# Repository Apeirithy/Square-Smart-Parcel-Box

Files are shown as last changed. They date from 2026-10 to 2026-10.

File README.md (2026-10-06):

# Square: Smart & Secure Parcel Box (IoT Edge-to-Cloud System)

An end-to-end Internet of Things (IoT) solution designed to secure residential package deliveries. Built around the ESP32-S3 microcontroller running FreeRTOS, this project integrates multi-sensor edge processing, physical actuation, and Firebase cloud synchronization to provide courier authentication, visual evidence capture, and remote management.

## Project Demonstration
* **Live System Demo & Technical Walkthrough:** [https://youtu.be/-ZhSldYhqhk]

<div align="center">
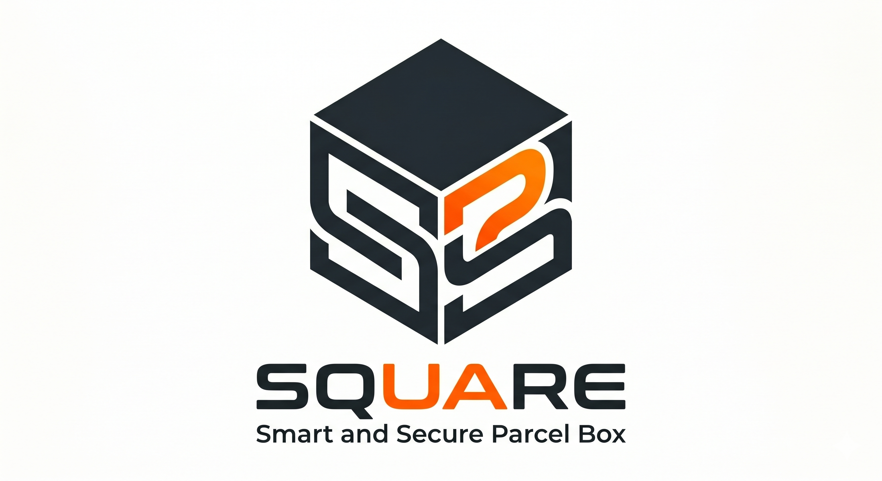
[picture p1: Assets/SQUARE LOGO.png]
Square Logo
  
</div>

## System Architecture & Key Implementations

### 1. Edge Processing & Real-Time Control (FreeRTOS)
The firmware leverages FreeRTOS to manage hardware concurrency and prevent resource collisions across the ESP32-S3's dual cores:
* **Task Isolation:** Separated network operations (Core 0) from time-critical hardware control and UI feedback (Core 1).
* **Multi-Tasking:** Managed independent tasks for Firebase synchronization (`Task_Network`), user input (`Task_Keypad_LED`), security state machine (`Task_StateMachine`), and media processing (`Task_Media`).
* **Resource Protection:** Utilized FreeRTOS Mutexes to secure shared buses (I2C, SPI) and Non-Volatile Storage (NVS) access.

### 2. Multi-Sensor Perception & Actuation
* **Authentication:** A $3\times4$ Matrix Keypad for local PIN input, securely validating against credentials cached in NVS.
* **Visual Evidence:** OV2640 camera captures MJPEG video during door opening and high-res photos upon closure, illuminated by a custom MOSFET-driven High-Power LED flash.
* **State Monitoring:** Magnetic reed switch detects door state, while a VL53L0X Time-of-Flight (ToF) sensor monitors internal capacity.
* **Security:** Actuates a 12V Solenoid lock via an isolated relay module upon successful authentication.

### 3. Cloud Synchronization & Failsafe Mechanisms
* **Firebase RTDB & Cloud Storage:** Synchronizes device status, delivery logs, and large media files (photo/video) using Server-Sent Events (SSE) and HTTPS.
* **Offline Buffering:** In the event of network disruption, all media and logs are buffered to a local MicroSD card using a custom FIFO auto-deletion queue. Uploads automatically resume once connectivity is restored.

<div align="center">
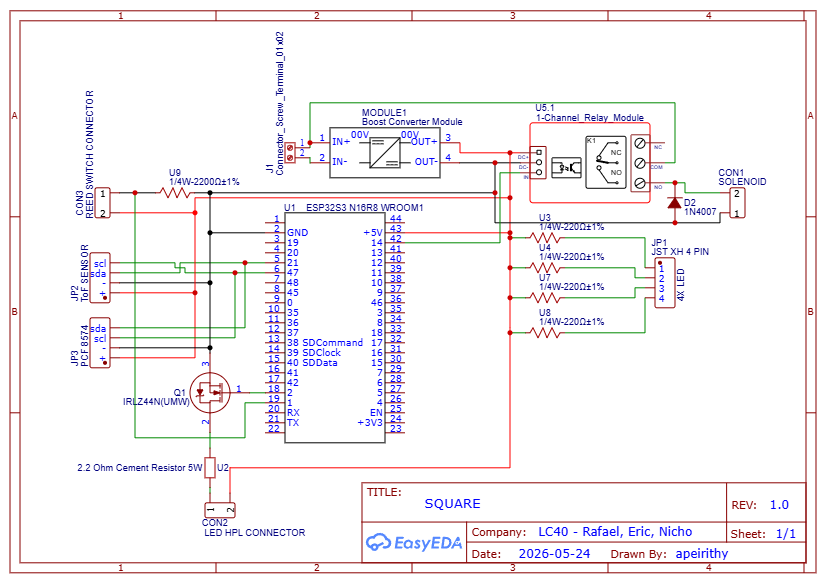
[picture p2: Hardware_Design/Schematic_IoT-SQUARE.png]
Hardware Schematic
  
</div>

## Hardware Engineering
* **Custom Enclosure & Mounts:** Key mechanical components, including camera mounts and sensor brackets, were custom-designed in Tinkercad and 3D printed (PLA).
* **Circuit Design:** Routed and planned the entire electrical schematic via EasyEDA, ensuring safe logic-level isolation for high-current actuators.

## Repository Contents
* **[`/Firmware_src`](./Firmware_src):** ESP32-S3 C++ source code (PlatformIO/Arduino framework).
* **[`/Hardware_Design`](./Hardware_Design):** Circuit schematics and 3D printable `.stl` files.
* **[`/Docs`](./Docs):** Comprehensive technical documentation, including the Final Report, Functional Specification Document (FSD), and Project Proposal.
* **[`/Assets`](./Assets):** Project logo and mobile application interface screenshots.

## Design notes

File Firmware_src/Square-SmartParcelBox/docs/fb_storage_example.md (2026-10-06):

```cpp
/*********
  Rui Santos & Sara Santos - Random Nerd Tutorials
  Complete instructions at: https://RandomNerdTutorials.com/esp32-cam-save-picture-firebase-storage/
  Permission is hereby granted, free of charge, to any person obtaining a copy of this software and associated documentation files. The above copyright notice and this permission notice shall be included in all copies or substantial portions of the Software.
  Based on the example provided by the ESP Firebase Client Library
*********/
#define ENABLE_USER_AUTH
#define ENABLE_STORAGE
#define ENABLE_FS

#include <Arduino.h>
#include <FirebaseClient.h>
#include <FS.h>
#include <LittleFS.h>
#include <WiFi.h>
#include <WiFiClientSecure.h>
#include "esp_camera.h"

#define WIFI_SSID "REPLACE_WITH_YOUR_SSID"
#define WIFI_PASSWORD "REPLACE_WITH_YOUR_PASSWORD"

#define API_KEY "REPLACE_WITH_YOUR_FIREBASE_PROJECT_API_KEY"
#define USER_EMAIL "REPLACE_WITH_FIREBASE_PROJECT_EMAIL_USER"
#define USER_PASSWORD "REPLACE_WITH_FIREBASE_PROJECT_USER_PASS"

// Define the Firebase storage bucket ID e.g bucket-name.appspot.com */
#define STORAGE_BUCKET_ID "REPLACE_WITH_STORAGE_BUCKET_ID"

// Photo path in filesystem and photo path in Firebase bucket
#define FILE_PHOTO_PATH "/photo.jpg"
#define BUCKET_PHOTO_PATH "/data/photo.jpg"

// User functions
void processData(AsyncResult &aResult);
void file_operation_callback(File &file, const char *filename, file_operating_mode mode);

FileConfig media_file(FILE_PHOTO_PATH, file_operation_callback); // Can be set later with media_file.setFile("/image.png", file_operation_callback);

File myFile;

// Authentication
UserAuth user_auth(API_KEY, USER_EMAIL, USER_PASSWORD, 3000 /* expire period in seconds (<3600) */);

// Firebase components
FirebaseApp app;
WiFiClientSecure ssl_client;
using AsyncClient = AsyncClientClass;
AsyncClient aClient(ssl_client);
Storage storage;

bool taskComplete = false;

AsyncResult storageResult;

// OV2640 camera module pins (CAMERA_MODEL_AI_THINKER)
#define PWDN_GPIO_NUM     32
#define RESET_GPIO_NUM    -1
#define XCLK_GPIO_NUM      0
#define SIOD_GPIO_NUM     26
#define SIOC_GPIO_NUM     27
#define Y9_GPIO_NUM       35
#define Y8_GPIO_NUM       34
#define Y7_GPIO_NUM       39
#define Y6_GPIO_NUM       36
#define Y5_GPIO_NUM       21
#define Y4_GPIO_NUM       19
#define Y3_GPIO_NUM       18
#define Y2_GPIO_NUM        5
#define VSYNC_GPIO_NUM    25
#define HREF_GPIO_NUM     23
#define PCLK_GPIO_NUM     22

boolean takeNewPhoto = true;

// Capture Photo and Save it to LittleFS
void capturePhotoSaveLittleFS( void ) {
  // Dispose first pictures because of bad quality
  camera_fb_t* fb = NULL;
  // Skip first 3 frames (increase/decrease number as needed).
  for (int i = 0; i < 10; i++) {
    fb = esp_camera_fb_get();
    esp_camera_fb_return(fb);
    fb = NULL;
  }
    
  // Take a new photo
  fb = NULL;  
  fb = esp_camera_fb_get();  
  if(!fb) {
    Serial.println("Camera capture failed");
    delay(1000);
    ESP.restart();
  }  

  // Photo file name
  Serial.printf("Picture file name: %s\n", FILE_PHOTO_PATH);
  File file = LittleFS.open(FILE_PHOTO_PATH, FILE_WRITE);

  // Insert the data in the photo file
  if (!file) {
    Serial.println("Failed to open file in writing mode");
  }
  else {
    file.write(fb->buf, fb->len); // payload (image), payload length
    Serial.print("The picture has been saved in ");
    Serial.print(FILE_PHOTO_PATH);
    Serial.print(" - Size: ");
    Serial.print(fb->len);
    Serial.println(" bytes");
  }
  // Close the file
  file.close();
  esp_camera_fb_return(fb);
  delay(100);
}

void initLittleFS(){
  if (!LittleFS.begin(true)) {
    Serial.println("An Error has occurred while mounting LittleFS");
    ESP.restart();
  }
  else {
    delay(500);
    Serial.println("LittleFS mounted successfully");
  }
}

void initWiFi(){
  WiFi.begin(WIFI_SSID, WIFI_PASSWORD);
  while (WiFi.status() != WL_CONNECTED) {
    delay(1000);
    Serial.println("Connecting to WiFi...");
  }
}

void initCamera(){
 // OV2640 camera module
  camera_config_t config;
  config.ledc_channel = LEDC_CHANNEL_0;
  config.ledc_timer = LEDC_TIMER_0;
  config.pin_d0 = Y2_GPIO_NUM;
  config.pin_d1 = Y3_GPIO_NUM;
  config.pin_d2 = Y4_GPIO_NUM;
  config.pin_d3 = Y5_GPIO_NUM;
  config.pin_d4 = Y6_GPIO_NUM;
  config.pin_d5 = Y7_GPIO_NUM;
  config.pin_d6 = Y8_GPIO_NUM;
  config.pin_d7 = Y9_GPIO_NUM;
  config.pin_xclk = XCLK_GPIO_NUM;
  config.pin_pclk = PCLK_GPIO_NUM;
  config.pin_vsync = VSYNC_GPIO_NUM;
  config.pin_href = HREF_GPIO_NUM;
  config.pin_sccb_sda = SIOD_GPIO_NUM;
  config.pin_sccb_scl = SIOC_GPIO_NUM;
  config.pin_pwdn = PWDN_GPIO_NUM;
  config.pin_reset = RESET_GPIO_NUM;
  config.xclk_freq_hz = 20000000;
  config.pixel_format = PIXFORMAT_JPEG;
  config.grab_mode = CAMERA_GRAB_LATEST;

  if (psramFound()) {
    config.frame_size = FRAMESIZE_UXGA;
    config.jpeg_quality = 10;
    config.fb_count = 1;
  } else {
    config.frame_size = FRAMESIZE_SVGA;
    config.jpeg_quality = 12;
    config.fb_count = 1;
  }
  // Camera init
  esp_err_t err = esp_camera_init(&config);
  if (err != ESP_OK) {
    Serial.printf("Camera init failed with error 0x%x", err);
    ESP.restart();
  }
  Serial.print("Camera init success");
}

void setup(){
    Serial.begin(115200);
    initWiFi();
    initCamera();

    Firebase.printf("Firebase Client v%s\n", FIREBASE_CLIENT_VERSION);

    initLittleFS();

    // Configure SSL client
    ssl_client.setInsecure();
    ssl_client.setConnectionTimeout(1000);
    ssl_client.setHandshakeTimeout(5);
    Serial.println("Initializing app...");
    initializeApp(aClient, app, getAuth(user_auth), processData, "🔐 authTask");

    app.getApp<Storage>(storage);

    Serial.println("Listing files in LittleFS:");
    File root = LittleFS.open("/");
    File file = root.openNextFile();
    while (file) {
        Serial.println(file.name());
        file = root.openNextFile();
    }

}

void loop(){
    // To maintain the authentication process.
    app.loop();

    if (app.ready() && !taskComplete && takeNewPhoto){
        taskComplete = true;
        takeNewPhoto = false;

        capturePhotoSaveLittleFS();
        
        // Async call with callback function.
        storage.upload(aClient, FirebaseStorage::Parent(STORAGE_BUCKET_ID, BUCKET_PHOTO_PATH), getFile(media_file), "image/jpg", processData, "⬆️  uploadTask");
    }
}

void processData(AsyncResult &aResult)
{
    // Exits when no result available when calling from the loop.
    if (!aResult.isResult())
        return;

    if (aResult.isEvent())
    {
        Firebase.printf("Event task: %s, msg: %s, code: %d\n", aResult.uid().c_str(), aResult.appEvent().message().c_str(), aResult.appEvent().code());
    }

    if (aResult.isDebug())
    {
        Firebase.printf("Debug task: %s, msg: %s\n", aResult.uid().c_str(), aResult.debug().c_str());
    }

    if (aResult.isError())
    {
        Firebase.printf("Error task: %s, msg: %s, code: %d\n", aResult.uid().c_str(), aResult.error().message().c_str(), aResult.error().code());
    }

    if (aResult.downloadProgress())
    {
        Firebase.printf("Downloaded, task: %s, %d%s (%d of %d)\n", aResult.uid().c_str(), aResult.downloadInfo().progress, "%", aResult.downloadInfo().downloaded, aResult.downloadInfo().total);
        if (aResult.downloadInfo().total == aResult.downloadInfo().downloaded)
        {
            Firebase.printf("Download task: %s, complete!✅️\n", aResult.uid().c_str());
        }
    }

    if (aResult.uploadProgress())
    {
        Firebase.printf("Uploaded, task: %s, %d%s (%d of %d)\n", aResult.uid().c_str(), aResult.uploadInfo().progress, "%", aResult.uploadInfo().uploaded, aResult.uploadInfo().total);
        if (aResult.uploadInfo().total == aResult.uploadInfo().uploaded)
        {
            Firebase.printf("Upload task: %s, complete!✅️\n", aResult.uid().c_str());
            Serial.print("Download URL: ");
            Serial.println(aResult.uploadInfo().downloadUrl);
        }
    }
}

void file_operation_callback(File &file, const char *filename, file_operating_mode mode){
    // FILE_OPEN_MODE_READ, FILE_OPEN_MODE_WRITE and FILE_OPEN_MODE_APPEND are defined in this library
    // MY_FS is defined in this example
    switch (mode)    {
    case file_mode_open_read:
        myFile = LittleFS.open(filename, "r");
        if (!myFile || !myFile.available()) {
            Serial.println("[ERROR] Failed to open file for reading");
        }
        break;
    case file_mode_open_write:
        myFile = LittleFS.open(filename, "w");
        break;
    case file_mode_open_append:
        myFile = LittleFS.open(filename, "a");
        break;
    case file_mode_remove:
        LittleFS.remove(filename);
        break;
    default:
        break;
    }
    // Set the internal FS object with global File object.
    file = myFile;
}
```

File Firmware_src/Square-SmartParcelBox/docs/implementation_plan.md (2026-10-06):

# Square Smart Parcel Box — Implementation Plan

## Background

Project ini adalah firmware ESP32-S3 untuk **Square Smart Parcel Box**, sebuah IoT parcel box yang memungkinkan kurir memasukkan paket dengan PIN terbatas, mengambil foto/video bukti, dan menyinkronkan data ke Firebase. Proyek menggunakan **PlatformIO + Arduino framework + FreeRTOS**.

Saat ini proyek masih kosong (hanya skeleton `main.cpp`). Rencana ini memecah seluruh firmware menjadi **10 fase** yang berurutan, di mana setiap fase menghasilkan komponen yang **bisa diuji secara independen** melalui serial monitor dan/atau unit test sederhana.

---

## Open Questions

> [!IMPORTANT]
> **Q1:** Apakah Anda ingin menggunakan framework testing formal (seperti `Unity` test framework bawaan PlatformIO) untuk unit test, atau cukup dengan test manual via serial monitor + sketch test sederhana?

> [!IMPORTANT]
> **Q2:** Apakah credentials (Wi-Fi SSID, Firebase keys, dll.) sudah tersedia dan siap diisi, atau harus dibuat placeholder terlebih dahulu?

> [!IMPORTANT]
> **Q3:** Untuk `upload_queue.txt`, apakah format setiap baris cukup berisi nama file (e.g., `img_1752587495.jpg`) satu per baris?

---

## Proposed Changes

Semua file baru mengikuti struktur dari Section 9 FSD:

```
src/
├── main.cpp
├── pins.h
├── credentials.h
├── config.h
├── hal/
│   ├── ws2812.h / .cpp
│   ├── relay.h / .cpp
│   ├── flash_led.h / .cpp
│   ├── reed_switch.h / .cpp
│   ├── tof.h / .cpp
│   ├── camera.h / .cpp
│   ├── sdcard.h / .cpp
│   ├── keypad_driver.h / .cpp
│   ├── keybuffer_indicator_driver.h / .cpp
│   └── nvs_store.h / .cpp
├── tasks/
│   ├── task_network.h / .cpp
│   ├── task_keypad_led.h / .cpp
│   ├── task_statemachine.h / .cpp
│   └── task_media.h / .cpp
├── state/
│   └── state_machine.h / .cpp
└── firebase/
    ├── fb_rtdb.h / .cpp
    └── fb_storage.h / .cpp
```

---

## Fase 0 — Foundation Files (Pin Definitions, Config, Credentials)

File-file dasar yang menjadi dependensi semua modul lain. **Tidak ada logika yang perlu diuji**, hanya konstanta.

---

### [NEW] [pins.h](file:///c:/Users/rafae/Forgor/ForgorEmbedded/PlatformIO/Square-SmartParcelBox/src/pins.h)

Satu-satunya sumber definisi pin. Semua GPIO, alamat I2C, dan pin PCF8574 didefinisikan di sini.

**Konstanta yang harus didefinisikan:**

| Kategori | Konstanta | Nilai | Catatan |
|---|---|---|---|
| WS2812 | `PIN_LED_WS2812` | `48` | RGB status LED |
| Relay | `PIN_RELAY_SOLENOID` | `14` | Active HIGH |
| Flash | `PIN_AUX_FLASH` | `2` | MOSFET gate |
| Reed Switch | `PIN_DOOR_SWITCH` | `1` | INPUT_PULLUP |
| I2C | `PIN_SDA` | `21` | Shared I2C bus |
| I2C | `PIN_SCL` | `47` | Shared I2C bus |
| I2C Addr | `I2C_ADDR_KEYPAD` | `0x20` | PCF8574 keypad |
| I2C Addr | `I2C_ADDR_LED_IND` | `0x21` | PCF8574 LED |
| I2C Addr | `I2C_ADDR_TOF` | `0x29` | VL53L0X |
| Camera | `PIN_CAM_D0` – `PIN_CAM_D7` | `11,9,8,10,12,18,17,16` | DVP data |
| Camera | `PIN_CAM_XCLK` | `15` | 20MHz clock |
| Camera | `PIN_CAM_PCLK` | `13` | Pixel clock |
| Camera | `PIN_CAM_VSYNC` | `6` | Vertical sync |
| Camera | `PIN_CAM_HREF` | `7` | Horizontal ref |
| Camera | `PIN_CAM_SIOD` | `4` | SCCB data |
| Camera | `PIN_CAM_SIOC` | `5` | SCCB clock |
| SD Card | `PIN_SD_DATA` | `40` | 1-bit mode |
| SD Card | `PIN_SD_CLK` | `39` | Clock |
| SD Card | `PIN_SD_CMD` | `38` | Command |

---

### [NEW] [credentials.h](file:///c:/Users/rafae/Forgor/ForgorEmbedded/PlatformIO/Square-SmartParcelBox/src/credentials.h)

Hardcoded credentials sesuai NCC-006.

**Konstanta yang harus didefinisikan:**

```cpp
#define WIFI_SSID             "your_ssid"
#define WIFI_PASSWORD         "your_password"
#define FIREBASE_DATABASE_URL "project-id-default-rtdb.firebaseio.com"
#define FIREBASE_WEBAPI_KEY   "your_web_api_key"
#define FIREBASE_STORAGE_BUCKET "your_bucket.appspot.com"
#define DEVICE_EMAIL          "device@example.com"
#define DEVICE_PASSWORD       "device_password"
#define USER_UID              "firebase_user_uid"
```

---

### [NEW] [config.h](file:///c:/Users/rafae/Forgor/ForgorEmbedded/PlatformIO/Square-SmartParcelBox/src/config.h)

Non-pin constants: thresholds, timeouts, sizes.

**Konstanta yang harus didefinisikan:**

| Konstanta | Nilai | Sumber FSD |
|---|---|---|
| `TOF_THRESHOLD_CM` | `38` | NCC-001, Section 4.3.7 |
| `TOF_BOX_WIDTH_CM` | `40` | Section 4.3.7 |
| `DOOR_TIMEOUT_MS` | `10000` | SFS-004 |
| `HEARTBEAT_INTERVAL_MS` | `30000` | NCC-008 |
| `WIFI_MAX_RETRIES` | `25` | SFS-006 |
| `WIFI_RETRY_DELAY_MS` | `300` | SFS-006 |
| `FLASH_WARMUP_MS` | `1000` | Section 4.3.5 |
| `SD_MIN_FREE_MB` | `50` | CVL-008 |
| `PIN_LENGTH` | `4` | ACC-001 |
| `RTDB_QUEUE_DEPTH` | `10` | Section 6.5 |
| `COMMAND_QUEUE_DEPTH` | `3` | Section 6.5 |
| `RETRY_FIRST_FAIL_MS` | `300000` (5 min) | Section 4.3.8 |
| `RETRY_SUBSEQUENT_MS` | `900000` (15 min) | Section 4.3.8 |
| `KEYPAD_DEBOUNCE_MS` | `200` | ACC-008 |
| `LED_ALT_INTERVAL_MS` | `250` | Section 4.2.3 |
| `ERROR_LOG_INTERVAL_MS` | `1000` | DBG-012 |
| `WS2812_BLINK_INTERVAL_MS` | `1000` | Section 6.7 |
| `RTOS_MIN_DELAY_MS` | `10` | SFS-009 |

---

## Fase 1 — HAL: Simple Output Drivers (WS2812, Relay, Flash LED)

Driver output sederhana yang **tidak memerlukan I2C** dan bisa diuji langsung.

---

### [NEW] [ws2812.h](file:///c:/Users/rafae/Forgor/ForgorEmbedded/PlatformIO/Square-SmartParcelBox/src/hal/ws2812.h) / [ws2812.cpp](file:///c:/Users/rafae/Forgor/ForgorEmbedded/PlatformIO/Square-SmartParcelBox/src/hal/ws2812.cpp)

WS2812 RGB LED driver. Wrapper around `Adafruit_NeoPixel`.

**Enum yang harus didefinisikan:**

```cpp
enum WS2812Pattern {
    WS2812_OFF,
    WS2812_RED_BLUE_BLINK,   // Startup: blink merah-biru tiap 1 detik
    WS2812_SOLID_BLUE,       // Wi-Fi connected
    WS2812_SOLID_GREEN,      // Firebase connected, no HW issues
    WS2812_SOLID_YELLOW,     // Firebase connected, partial HW issues
    WS2812_SOLID_PURPLE,     // Offline mode with NVS pins
    WS2812_SOLID_RED          // Fatal error / STATE_ERROR
};
```

**Fungsi yang harus dibuat:**

| Fungsi | Signature | Deskripsi | Cara Uji |
|---|---|---|---|
| `ws2812_init` | `bool ws2812_init()` | Inisialisasi NeoPixel pada `PIN_LED_WS2812`. Return `true` jika berhasil. | Panggil di `setup()`, cek LED menyala. |
| `ws2812_set_pattern` | `void ws2812_set_pattern(WS2812Pattern pattern)` | Set pola LED saat ini. Menyimpan pattern ke variable internal. | Panggil dengan berbagai pattern, verifikasi warna LED secara visual. |
| `ws2812_update` | `void ws2812_update()` | Dipanggil di loop task untuk mengupdate animasi (blink). Harus non-blocking, menggunakan `millis()`. | Panggil dalam loop, verifikasi blink bekerja. |

---

### [NEW] [relay.h](file:///c:/Users/rafae/Forgor/ForgorEmbedded/PlatformIO/Square-SmartParcelBox/src/hal/relay.h) / [relay.cpp](file:///c:/Users/rafae/Forgor/ForgorEmbedded/PlatformIO/Square-SmartParcelBox/src/hal/relay.cpp)

Solenoid relay driver. Active HIGH.

**Fungsi yang harus dibuat:**

| Fungsi | Signature | Deskripsi | Cara Uji |
|---|---|---|---|
| `relay_init` | `bool relay_init()` | Inisialisasi GPIO `PIN_RELAY_SOLENOID` sebagai OUTPUT, set LOW (locked). Return `true`. | Panggil di `setup()`, pastikan solenoid terkunci. |
| `relay_unlock` | `void relay_unlock()` | Set pin HIGH untuk membuka solenoid. | Panggil, verifikasi solenoid terbuka. |
| `relay_lock` | `void relay_lock()` | Set pin LOW untuk mengunci solenoid. | Panggil, verifikasi solenoid terkunci. |
| `relay_is_unlocked` | `bool relay_is_unlocked()` | Return status pin saat ini (`HIGH` = unlocked). | Panggil setelah `unlock`/`lock`, verifikasi via Serial. |

---

### [NEW] [flash_led.h](file:///c:/Users/rafae/Forgor/ForgorEmbedded/PlatformIO/Square-SmartParcelBox/src/hal/flash_led.h) / [flash_led.cpp](file:///c:/Users/rafae/Forgor/ForgorEmbedded/PlatformIO/Square-SmartParcelBox/src/hal/flash_led.cpp)

Auxiliary flash LED driver (MOSFET-driven). Active HIGH.

**Fungsi yang harus dibuat:**

| Fungsi | Signature | Deskripsi | Cara Uji |
|---|---|---|---|
| `flash_led_init` | `bool flash_led_init()` | Inisialisasi GPIO `PIN_AUX_FLASH` sebagai OUTPUT, set LOW (off). Return `true`. | Panggil di `setup()`. |
| `flash_led_on` | `void flash_led_on()` | Nyalakan flash LED (HIGH). | Panggil, verifikasi LED menyala. |
| `flash_led_off` | `void flash_led_off()` | Matikan flash LED (LOW). | Panggil, verifikasi LED mati. |

---

## Fase 2 — HAL: Simple Input Driver (Reed Switch)

---

### [NEW] [reed_switch.h](file:///c:/Users/rafae/Forgor/ForgorEmbedded/PlatformIO/Square-SmartParcelBox/src/hal/reed_switch.h) / [reed_switch.cpp](file:///c:/Users/rafae/Forgor/ForgorEmbedded/PlatformIO/Square-SmartParcelBox/src/hal/reed_switch.cpp)

Magnetic reed switch driver. Closed = HIGH, Open = LOW.

**Fungsi yang harus dibuat:**

| Fungsi | Signature | Deskripsi | Cara Uji |
|---|---|---|---|
| `reed_switch_init` | `bool reed_switch_init()` | Inisialisasi GPIO `PIN_DOOR_SWITCH` sebagai `INPUT_PULLUP`. Return `true`. | Panggil di `setup()`. |
| `reed_switch_is_closed` | `bool reed_switch_is_closed()` | Return `true` jika pin HIGH (pintu tertutup). | Buka/tutup pintu, print ke Serial. |
| `reed_switch_is_open` | `bool reed_switch_is_open()` | Return `true` jika pin LOW (pintu terbuka). Kebalikan dari `is_closed`. | Buka/tutup pintu, print ke Serial. |

---

## Fase 3 — HAL: I2C Drivers (Keypad, LED Indicator, ToF)

Semua perangkat I2C pada bus yang sama. Memerlukan `I2C_Mutex` untuk akses bersama, tetapi di fase ini diuji **tanpa mutex** (single-threaded).

---

### [NEW] [keypad_driver.h](file:///c:/Users/rafae/Forgor/ForgorEmbedded/PlatformIO/Square-SmartParcelBox/src/hal/keypad_driver.h) / [keypad_driver.cpp](file:///c:/Users/rafae/Forgor/ForgorEmbedded/PlatformIO/Square-SmartParcelBox/src/hal/keypad_driver.cpp)

Custom 3x4 matrix keypad library via PCF8574 (ACC-009). Mengimplementasi row-scanning dengan debounce (ACC-008).

**Fungsi yang harus dibuat:**

| Fungsi | Signature | Deskripsi | Cara Uji |
|---|---|---|---|
| `keypad_init` | `bool keypad_init(TwoWire &wire)` | Inisialisasi I2C pada alamat `I2C_ADDR_KEYPAD`. Verifikasi PCF8574 merespons. Return `true`/`false`. | Panggil di `setup()`, cek log `SUCCESS`/`FAILED`. |
| `keypad_scan` | `char keypad_scan()` | Scan satu siklus penuh matrix keypad. Return karakter tombol yang ditekan (`'0'`–`'9'`, `'*'`, `'#'`) atau `'\0'` jika tidak ada. Implementasi debounce internal. HARUS mengabaikan `'*'` dan `'#'` (ACC-010). | Panggil dalam loop, print karakter ke Serial. Verifikasi setiap tekan = satu karakter (ACC-008). |
| `keypad_is_available` | `bool keypad_is_available()` | Return `true` jika init berhasil dan PCF8574 merespons. | Cabut I2C, verifikasi return `false`. |

**Detail implementasi `keypad_scan`:**
1. Untuk setiap row (R1-R4): set row LOW, baca kolom (C1-C3).
2. Jika ada kolom LOW, decode posisi ke karakter.
3. Debounce: hanya return karakter jika tombol stabil selama `KEYPAD_DEBOUNCE_MS`.
4. Edge detection: hanya return karakter pada transisi press→release atau idle→press, BUKAN saat hold.
5. Ignore `'*'` dan `'#'` → return `'\0'`.

---

### [NEW] [keybuffer_indicator_driver.h](file:///c:/Users/rafae/Forgor/ForgorEmbedded/PlatformIO/Square-SmartParcelBox/src/hal/keybuffer_indicator_driver.h) / [keybuffer_indicator_driver.cpp](file:///c:/Users/rafae/Forgor/ForgorEmbedded/PlatformIO/Square-SmartParcelBox/src/hal/keybuffer_indicator_driver.cpp)

4x LED indicator via PCF8574 (Active LOW).

**Fungsi yang harus dibuat:**

| Fungsi | Signature | Deskripsi | Cara Uji |
|---|---|---|---|
| `led_indicator_init` | `bool led_indicator_init(TwoWire &wire)` | Inisialisasi I2C pada alamat `I2C_ADDR_LED_IND`. Set semua LED OFF (all bits HIGH karena active LOW). Return `true`/`false`. | Panggil, verifikasi semua LED mati. |
| `led_indicator_set_count` | `void led_indicator_set_count(uint8_t count)` | Nyalakan LED 0 s/d `count-1`. `count=0` semua mati, `count=4` semua nyala. | Panggil dengan 0–4, verifikasi visual. |
| `led_indicator_all_off` | `void led_indicator_all_off()` | Matikan semua LED. Shortcut untuk `set_count(0)`. | Verifikasi visual. |
| `led_indicator_alternating_pattern` | `void led_indicator_alternating_pattern()` | Animasi bergantian kiri-kanan sesuai Section 4.2.3 (250ms interval). Non-blocking, gunakan `millis()`. | Panggil dalam loop, verifikasi pola. |
| `led_indicator_stop_pattern` | `void led_indicator_stop_pattern()` | Hentikan pola animasi dan matikan semua LED. | Panggil setelah animasi berjalan. |
| `led_indicator_is_available` | `bool led_indicator_is_available()` | Return `true` jika init berhasil. | Cek return value. |

---

### [NEW] [tof.h](file:///c:/Users/rafae/Forgor/ForgorEmbedded/PlatformIO/Square-SmartParcelBox/src/hal/tof.h) / [tof.cpp](file:///c:/Users/rafae/Forgor/ForgorEmbedded/PlatformIO/Square-SmartParcelBox/src/hal/tof.cpp)

VL53L0X Time-of-Flight sensor driver via `Adafruit_VL53L0X`.

**Fungsi yang harus dibuat:**

| Fungsi | Signature | Deskripsi | Cara Uji |
|---|---|---|---|
| `tof_init` | `bool tof_init(TwoWire &wire)` | Inisialisasi VL53L0X pada alamat `I2C_ADDR_TOF`. Return `true`/`false`. | Panggil, cek log. |
| `tof_read_distance_cm` | `int16_t tof_read_distance_cm()` | Baca jarak dalam cm. Return `-1` jika gagal/timeout. | Letakkan objek di depan sensor, print jarak. |
| `tof_is_full` | `bool tof_is_full()` | Return `true` jika `tof_read_distance_cm() < TOF_THRESHOLD_CM`. Sesuai NCC-001. | Blokir/buka sensor, verifikasi output. |
| `tof_is_available` | `bool tof_is_available()` | Return `true` jika init berhasil. | Cek return value. |

---

## Fase 4 — HAL: Camera & SD Card

Komponen yang lebih kompleks, masing-masing memiliki banyak fungsi.

---

### [NEW] [camera.h](file:///c:/Users/rafae/Forgor/ForgorEmbedded/PlatformIO/Square-SmartParcelBox/src/hal/camera.h) / [camera.cpp](file:///c:/Users/rafae/Forgor/ForgorEmbedded/PlatformIO/Square-SmartParcelBox/src/hal/camera.cpp)

OV2640 camera driver. Mendukung foto (UXGA/JPG 1600×1200) dan video (VGA/MJPEG 640×480).

**Fungsi yang harus dibuat:**

| Fungsi | Signature | Deskripsi | Cara Uji |
|---|---|---|---|
| `camera_init` | `bool camera_init()` | Inisialisasi kamera OV2640 dengan konfigurasi pin dari `pins.h`. Gunakan PSRAM untuk frame buffer. Default resolusi UXGA JPG. Return `true`/`false`. | Panggil, cek log SUCCESS/FAILED. |
| `camera_capture_photo` | `camera_fb_t* camera_capture_photo()` | Set resolusi ke UXGA, ambil satu frame. Return pointer ke frame buffer (caller harus memanggil `camera_return_fb`). Return `NULL` jika gagal. | Panggil, verifikasi `fb->len > 0`. |
| `camera_return_fb` | `void camera_return_fb(camera_fb_t* fb)` | Kembalikan frame buffer ke pool. | Panggil setelah `capture_photo`. |
| `camera_set_resolution_photo` | `void camera_set_resolution_photo()` | Set resolusi ke UXGA (1600×1200) JPG. | Panggil, ambil foto, verifikasi resolusi. |
| `camera_set_resolution_video` | `void camera_set_resolution_video()` | Set resolusi ke VGA (640×480) JPG (untuk MJPEG frames). | Panggil, ambil frame, verifikasi resolusi. |
| `camera_is_available` | `bool camera_is_available()` | Return `true` jika init berhasil. | Cek return value. |

---

### [NEW] [sdcard.h](file:///c:/Users/rafae/Forgor/ForgorEmbedded/PlatformIO/Square-SmartParcelBox/src/hal/sdcard.h) / [sdcard.cpp](file:///c:/Users/rafae/Forgor/ForgorEmbedded/PlatformIO/Square-SmartParcelBox/src/hal/sdcard.cpp)

MicroSD card driver. 1-bit SD_MMC mode. Mencakup file I/O, upload queue, dan FIFO cleanup.

**Fungsi yang harus dibuat:**

| Fungsi | Signature | Deskripsi | Cara Uji |
|---|---|---|---|
| `sdcard_init` | `bool sdcard_init()` | Mount SD card via `SD_MMC` 1-bit mode. Log tipe dan ukuran kartu (DBG-010). Return `true`/`false`. | Panggil, cek log. |
| `sdcard_write_test` | `bool sdcard_write_test()` | Tulis dan baca file dummy untuk verifikasi (DBG-008). Return `true` jika PASSED. | Panggil, cek log. |
| `sdcard_save_file` | `bool sdcard_save_file(const char* dir_path, const char* filename, const uint8_t* data, size_t len)` | Buat direktori `dir_path` jika belum ada, tulis data ke `dir_path/filename`. Return `true`/`false`. | Tulis data dummy, baca kembali, bandingkan. |
| `sdcard_read_file` | `bool sdcard_read_file(const char* filepath, uint8_t** out_data, size_t* out_len)` | Baca file ke buffer yang di-allocate (caller harus `free()`). Return `true`/`false`. | Baca file yang sudah ditulis, verifikasi isi. |
| `sdcard_file_exists` | `bool sdcard_file_exists(const char* filepath)` | Cek apakah file ada. | Cek file yang ada dan tidak ada. |
| `sdcard_delete_file` | `bool sdcard_delete_file(const char* filepath)` | Hapus file. Return `true`/`false`. | Hapus file, verifikasi tidak ada lagi. |
| `sdcard_delete_dir` | `bool sdcard_delete_dir(const char* dir_path)` | Hapus direktori beserta isinya. Return `true`/`false`. | Buat dir+file, hapus dir, verifikasi. |
| `sdcard_get_free_mb` | `uint32_t sdcard_get_free_mb()` | Return sisa ruang kosong dalam MB. | Print, verifikasi masuk akal. |
| `sdcard_queue_push_back` | `bool sdcard_queue_push_back(const char* filename)` | Tambahkan `filename` ke akhir `upload_queue.txt`. | Tambah beberapa entry, baca file, verifikasi urutan. |
| `sdcard_queue_push_front` | `bool sdcard_queue_push_front(const char* filename)` | Tambahkan `filename` ke depan `upload_queue.txt` (untuk prioritas on-demand). | Tambah entry, verifikasi posisi pertama. |
| `sdcard_queue_pop_front` | `bool sdcard_queue_pop_front(char* out_filename, size_t max_len)` | Ambil dan hapus entry pertama dari `upload_queue.txt`. Return `true` jika ada entry. | Push beberapa, pop satu per satu, verifikasi urutan FIFO. |
| `sdcard_queue_peek_front` | `bool sdcard_queue_peek_front(char* out_filename, size_t max_len)` | Lihat entry pertama tanpa menghapus. | Peek, verifikasi tidak hilang setelah peek. |
| `sdcard_queue_remove` | `bool sdcard_queue_remove(const char* filename)` | Hapus entry spesifik dari queue (untuk abort on-demand). | Push 3, remove tengah, verifikasi. |
| `sdcard_queue_is_empty` | `bool sdcard_queue_is_empty()` | Return `true` jika queue kosong. | Cek saat kosong dan saat ada isi. |
| `sdcard_fifo_cleanup` | `void sdcard_fifo_cleanup()` | Paired FIFO deletion (CVL-007, CVL-008): hapus pasangan img+vid terlama sampai free space ≥ `SD_MIN_FREE_MB`. | Buat banyak file dummy, panggil cleanup, verifikasi file terlama terhapus. |
| `sdcard_is_available` | `bool sdcard_is_available()` | Return `true` jika init berhasil. | Cek return value. |
| `sdcard_get_type_string` | `const char* sdcard_get_type_string()` | Return string tipe kartu ("SDHC", "SD", dll). | Print ke Serial. |
| `sdcard_get_size_mb` | `uint32_t sdcard_get_size_mb()` | Return ukuran kartu dalam MB. | Print ke Serial. |

---

## Fase 5 — HAL: NVS Storage

---

### [NEW] [nvs_store.h](file:///c:/Users/rafae/Forgor/ForgorEmbedded/PlatformIO/Square-SmartParcelBox/src/hal/nvs_store.h) / [nvs_store.cpp](file:///c:/Users/rafae/Forgor/ForgorEmbedded/PlatformIO/Square-SmartParcelBox/src/hal/nvs_store.cpp)

NVS Preferences wrapper untuk menyimpan active_pins sebagai JSON string (max 512 bytes). Menggunakan `ArduinoJson` untuk serialisasi.

**Fungsi yang harus dibuat:**

| Fungsi | Signature | Deskripsi | Cara Uji |
|---|---|---|---|
| `nvs_store_init` | `bool nvs_store_init()` | Inisialisasi Preferences namespace. Baca `active_pins` string jika ada. Return `true`/`false`. Log jumlah PIN aktif (DBG-011). | Panggil, cek log. |
| `nvs_store_get_pin_count` | `int nvs_store_get_pin_count()` | Return jumlah PIN aktif yang tersimpan. | Tambah PIN, verifikasi count. |
| `nvs_store_has_pins` | `bool nvs_store_has_pins()` | Return `true` jika ada minimal 1 PIN aktif. | Cek saat kosong dan saat ada PIN. |
| `nvs_store_verify_pin` | `bool nvs_store_verify_pin(const char* pin)` | Verifikasi PIN: return `true` jika PIN ada dan `used_quota < quota`. | Simpan PIN q=3 u=1, verifikasi true. Simpan PIN q=1 u=1, verifikasi false. |
| `nvs_store_increment_used` | `bool nvs_store_increment_used(const char* pin)` | Increment `used_quota` PIN. Jika `used_quota >= quota`, hapus PIN dari NVS (ACC-007). Return `true` jika berhasil. | Increment, cek count berkurang setelah habis. |
| `nvs_store_get_remaining_quota` | `int nvs_store_get_remaining_quota(const char* pin)` | Return sisa quota (`quota - used_quota`). Return `-1` jika PIN tidak ditemukan. | Cek sebelum/sesudah increment. |
| `nvs_store_save_pin` | `bool nvs_store_save_pin(const char* pin, int quota, int used_quota)` | Simpan/update satu PIN ke NVS. | Simpan, baca kembali, verifikasi. |
| `nvs_store_save_all_pins` | `bool nvs_store_save_all_pins(const char* json_str)` | Overwrite seluruh `active_pins` dengan JSON string baru (untuk sinkronisasi dari Firebase). | Simpan JSON, baca count, verifikasi. |
| `nvs_store_get_all_pins_json` | `String nvs_store_get_all_pins_json()` | Return JSON string dari semua active_pins saat ini. | Print ke Serial, verifikasi format. |
| `nvs_store_delete_pin` | `bool nvs_store_delete_pin(const char* pin)` | Hapus satu PIN spesifik dari NVS. | Hapus, verifikasi count berkurang. |
| `nvs_store_clear_all` | `void nvs_store_clear_all()` | Hapus semua PIN (untuk debugging). | Panggil, verifikasi `has_pins()` false. |
| `nvs_store_is_available` | `bool nvs_store_is_available()` | Return `true` jika init berhasil. | Cek return value. |

---

## Fase 6 — State Machine

---

### [NEW] [state_machine.h](file:///c:/Users/rafae/Forgor/ForgorEmbedded/PlatformIO/Square-SmartParcelBox/src/state/state_machine.h) / [state_machine.cpp](file:///c:/Users/rafae/Forgor/ForgorEmbedded/PlatformIO/Square-SmartParcelBox/src/state/state_machine.cpp)

State enum dan transition logic sesuai Section 6.6.

**Enum yang harus didefinisikan:**

```cpp
enum SystemState {
    STATE_START,
    STATE_IDLE,
    STATE_DELIVERY,
    STATE_ONDEMAND,
    STATE_ERROR
};

// Command enum untuk CommandQueue
enum RemoteCommand {
    CMD_NONE,
    CMD_UNLOCK,
    CMD_LOCK,
    CMD_LOCK_AND_UNLOCK,   // Conflict: prioritas lock (Section 5.1)
    CMD_REQUEST_PHOTO,
    CMD_REQUEST_VIDEO
};
```

**Fungsi yang harus dibuat:**

| Fungsi | Signature | Deskripsi | Cara Uji |
|---|---|---|---|
| `sm_init` | `void sm_init()` | Set state awal ke `STATE_START`. | Panggil, cek state. |
| `sm_get_state` | `SystemState sm_get_state()` | Return state saat ini. | Cek setelah init. |
| `sm_transition_to` | `bool sm_transition_to(SystemState new_state)` | Validasi dan eksekusi transisi. Return `false` jika transisi illegal (e.g., dari `STATE_ERROR` ke manapun). Log transisi ke Serial. | Coba semua transisi valid dan invalid. |
| `sm_is_idle` | `bool sm_is_idle()` | Shortcut: return `state == STATE_IDLE`. | Cek di berbagai state. |
| `sm_is_error` | `bool sm_is_error()` | Shortcut: return `state == STATE_ERROR`. | Cek di berbagai state. |
| `sm_get_state_name` | `const char* sm_get_state_name(SystemState state)` | Return string nama state untuk logging (e.g., `"STATE_IDLE"`). | Print semua state names. |

**Tabel transisi valid (enforce di `sm_transition_to`):**

| From | To | Valid? |
|---|---|---|
| `STATE_START` | `STATE_IDLE` | ✅ |
| `STATE_START` | `STATE_ERROR` | ✅ |
| `STATE_IDLE` | `STATE_DELIVERY` | ✅ |
| `STATE_IDLE` | `STATE_ONDEMAND` | ✅ |
| `STATE_IDLE` | `STATE_ERROR` | ✅ |
| `STATE_DELIVERY` | `STATE_IDLE` | ✅ |
| `STATE_DELIVERY` | `STATE_ERROR` | ✅ |
| `STATE_ONDEMAND` | `STATE_IDLE` | ✅ |
| `STATE_ERROR` | * | ❌ (dead state) |

---

## Fase 7 — Firebase Modules

---

### [NEW] [fb_rtdb.h](file:///c:/Users/rafae/Forgor/ForgorEmbedded/PlatformIO/Square-SmartParcelBox/src/firebase/fb_rtdb.h) / [fb_rtdb.cpp](file:///c:/Users/rafae/Forgor/ForgorEmbedded/PlatformIO/Square-SmartParcelBox/src/firebase/fb_rtdb.cpp)

Semua operasi Firebase Realtime Database. Menggunakan `FirebaseClient` library.

**Fungsi yang harus dibuat:**

| Fungsi | Signature | Deskripsi | Cara Uji |
|---|---|---|---|
| `fb_rtdb_init` | `bool fb_rtdb_init()` | Autentikasi Firebase via email/password (`DEVICE_EMAIL`, `DEVICE_PASSWORD`). Setup SSL client. Return `true`/`false`. | Panggil, cek log autentikasi berhasil. |
| `fb_rtdb_create_device_entry` | `bool fb_rtdb_create_device_entry(const char* mac_address)` | Buat entry device baru di RTDB path `users/{USER_UID}/devices/{mac_address}/` dengan sub-entry kosong (delivery_logs, remote_sync, status). | Panggil, verifikasi di Firebase Console. |
| `fb_rtdb_update_heartbeat` | `bool fb_rtdb_update_heartbeat(const char* mac_address, const char* timestamp)` | Update `status/last_heartbeat` dengan timestamp saat ini. | Panggil tiap 30 detik, verifikasi di Console. |
| `fb_rtdb_update_status` | `bool fb_rtdb_update_status(const char* mac_address, const char* key, bool value)` | Update field status (`isOpen`, `isUnlocked`, `isFull`). | Update, verifikasi di Console. |
| `fb_rtdb_add_delivery_log` | `bool fb_rtdb_add_delivery_log(const char* mac_address, const char* timestamp, const char* used_pin, const char* event_type, const char* photo_url)` | Tambah entry delivery log baru. | Tambah, verifikasi di Console. |
| `fb_rtdb_update_delivery_video_url` | `bool fb_rtdb_update_delivery_video_url(const char* mac_address, const char* timestamp, const char* video_url)` | Update `video_evidence_url` pada delivery log tertentu. | Update, verifikasi di Console. |
| `fb_rtdb_stream_start` | `bool fb_rtdb_stream_start(const char* mac_address)` | Start SSE stream pada path `users/{USER_UID}/devices/{mac_address}/remote_sync`. | Panggil, verifikasi koneksi di log. |
| `fb_rtdb_stream_loop` | `void fb_rtdb_stream_loop()` | Proses event stream. Parse data yang masuk dan kirim ke CommandQueue / update NVS pins. | Ubah data di Console, verifikasi event diterima. |
| `fb_rtdb_is_connected` | `bool fb_rtdb_is_connected()` | Return `true` jika autentikasi sukses dan koneksi aktif. | Cek saat connected/disconnected. |
| `fb_rtdb_clear_command` | `bool fb_rtdb_clear_command(const char* mac_address, const char* command_key, const char* reset_value)` | Reset command field (`unlock`→`false`, `request_video_id`→`""`, dll). | Reset, verifikasi di Console. |
| `fb_rtdb_increment_pin_used_quota` | `bool fb_rtdb_increment_pin_used_quota(const char* mac_address, const char* pin)` | Increment `used_quota` PIN di Firebase (ACC-006). | Increment, verifikasi di Console. |
| `fb_rtdb_delete_pin` | `bool fb_rtdb_delete_pin(const char* mac_address, const char* pin)` | Hapus PIN dari Firebase (ACC-007). | Hapus, verifikasi di Console. |
| `fb_rtdb_get_mac_address` | `String fb_rtdb_get_mac_address()` | Return MAC address ESP32 sebagai string hex 12-digit tanpa separator. | Print, verifikasi. |

---

### [NEW] [fb_storage.h](file:///c:/Users/rafae/Forgor/ForgorEmbedded/PlatformIO/Square-SmartParcelBox/src/firebase/fb_storage.h) / [fb_storage.cpp](file:///c:/Users/rafae/Forgor/ForgorEmbedded/PlatformIO/Square-SmartParcelBox/src/firebase/fb_storage.cpp)

Firebase Cloud Storage upload operations.

**Fungsi yang harus dibuat:**

| Fungsi | Signature | Deskripsi | Cara Uji |
|---|---|---|---|
| `fb_storage_init` | `bool fb_storage_init()` | Setup Firebase Storage client. Return `true`/`false`. | Panggil, cek log. |
| `fb_storage_upload_file` | `String fb_storage_upload_file(const char* mac_address, const char* timestamp, const char* local_filepath, const char* content_type)` | Upload file dari SD card ke path `users/{USER_UID}/devices/{mac_address}/storage/{timestamp}/{filename}`. Return download URL jika sukses, empty string jika gagal. | Upload foto test, verifikasi di Firebase Console. |
| `fb_storage_is_available` | `bool fb_storage_is_available()` | Return `true` jika init berhasil. | Cek return value. |

---

## Fase 8 — RTOS IPC (Queues & Mutexes)

Mendefinisikan dan membuat semua RTOS primitif sebelum task dibuat.

---

### RTOS IPC — Didefinisikan di [main.cpp](file:///c:/Users/rafae/Forgor/ForgorEmbedded/PlatformIO/Square-SmartParcelBox/src/main.cpp) sebagai global

**Objek RTOS yang harus dibuat (sebagai `extern` di header masing-masing task):**

| Nama | Tipe | Konfigurasi | Digunakan Oleh |
|---|---|---|---|
| `RTDBQueue` | `QueueHandle_t` | Depth: 10, item size: struct `RTDBWriteRequest` | Task_Network (consumer), Task_StateMachine (producer) |
| `CommandQueue` | `QueueHandle_t` | Depth: 3, item size: `RemoteCommand` enum | Task_Network (producer), Task_StateMachine (consumer) |
| `I2C_Mutex` | `SemaphoreHandle_t` | Mutex | Task_Keypad_LED, Task_StateMachine (ToF) |
| `SD_Mutex` | `SemaphoreHandle_t` | Mutex | Task_Network, Task_Media |
| `NVS_Mutex` | `SemaphoreHandle_t` | Mutex | Task_Network, Task_StateMachine |

**Struct untuk RTDBQueue:**

```cpp
enum RTDBWriteType {
    RTDB_HEARTBEAT,
    RTDB_STATUS_BOOL,
    RTDB_DELIVERY_LOG,
    RTDB_CLEAR_COMMAND,
    RTDB_INCREMENT_PIN,
    RTDB_DELETE_PIN,
    RTDB_UPDATE_VIDEO_URL
};

struct RTDBWriteRequest {
    RTDBWriteType type;
    char key[32];          // status key or PIN or command key
    char value_str[128];   // timestamp, URL, etc.
    bool value_bool;       // for boolean status
};
```

**Cara Uji:** Buat program test sederhana yang membuat queue, push/pop item, verifikasi via Serial.

---

## Fase 9 — RTOS Tasks

Setiap task berjalan di core yang ditentukan sesuai Section 6.4.

---

### [NEW] [task_keypad_led.h](file:///c:/Users/rafae/Forgor/ForgorEmbedded/PlatformIO/Square-SmartParcelBox/src/tasks/task_keypad_led.h) / [task_keypad_led.cpp](file:///c:/Users/rafae/Forgor/ForgorEmbedded/PlatformIO/Square-SmartParcelBox/src/tasks/task_keypad_led.cpp)

**Priority 4 (Highest), Core 1.** I2C: Keypad + LED Indicator.

**Fungsi yang harus dibuat:**

| Fungsi | Signature | Deskripsi | Cara Uji |
|---|---|---|---|
| `task_keypad_led_entry` | `void task_keypad_led_entry(void* pvParameters)` | FreeRTOS task entry point. Loop: scan keypad (dengan I2C_Mutex), update LED count, jika 4 digit terkumpul → set flag/notify Task_StateMachine. | Jalankan task, tekan tombol, verifikasi LED dan log Serial. |
| `task_keypad_led_get_buffer` | `const char* task_keypad_led_get_buffer()` | Return pointer ke 4-digit buffer saat ini. | Tekan 4 digit, baca buffer. |
| `task_keypad_led_clear_buffer` | `void task_keypad_led_clear_buffer()` | Reset buffer ke kosong dan matikan semua LED. | Panggil, verifikasi buffer kosong. |
| `task_keypad_led_is_buffer_full` | `bool task_keypad_led_is_buffer_full()` | Return `true` jika 4 digit sudah dimasukkan. | Tekan 4 digit, verifikasi. |
| `task_keypad_led_set_enabled` | `void task_keypad_led_set_enabled(bool enabled)` | Enable/disable scanning (disable saat tidak di STATE_IDLE). | Disable, tekan tombol, verifikasi tidak terekam. |

**Loop utama:**
1. `vTaskDelay(pdMS_TO_TICKS(RTOS_MIN_DELAY_MS))` (SFS-009)
2. Acquire `I2C_Mutex`
3. `key = keypad_scan()`
4. Jika `key != '\0'`: tambah ke buffer, update `led_indicator_set_count(buffer_len)`
5. Release `I2C_Mutex`
6. Jika `buffer_len == 4`: set flag `buffer_full = true`

---

### [NEW] [task_statemachine.h](file:///c:/Users/rafae/Forgor/ForgorEmbedded/PlatformIO/Square-SmartParcelBox/src/tasks/task_statemachine.h) / [task_statemachine.cpp](file:///c:/Users/rafae/Forgor/ForgorEmbedded/PlatformIO/Square-SmartParcelBox/src/tasks/task_statemachine.cpp)

**Priority 3, Core 1.** Central coordinator.

**Fungsi yang harus dibuat:**

| Fungsi | Signature | Deskripsi | Cara Uji |
|---|---|---|---|
| `task_sm_entry` | `void task_sm_entry(void* pvParameters)` | FreeRTOS task entry point. Main state machine loop. | Jalankan, monitor transisi state via Serial. |
| `task_sm_handle_idle` | `void task_sm_handle_idle()` | Handle STATE_IDLE: cek buffer keypad penuh → verifikasi PIN → transition. Cek CommandQueue → handle remote commands. Trigger FIFO cleanup sekali. | Masukkan PIN, verifikasi transisi. |
| `task_sm_handle_delivery` | `void task_sm_handle_delivery(const char* pin_used)` | Handle STATE_DELIVERY: unlock, wait door open (timeout 10s), wait door close, lock, notify Task_Media, read ToF, enqueue RTDB writes, wait upload. | Simulasi buka/tutup pintu. |
| `task_sm_handle_ondemand` | `void task_sm_handle_ondemand(const char* timestamp)` | Handle STATE_ONDEMAND: notify Task_Media untuk foto, read ToF, enqueue RTDB writes. | Kirim command via Firebase Console. |
| `task_sm_handle_error` | `void task_sm_handle_error()` | Handle STATE_ERROR: log fatal error tiap 1 detik (DBG-012). WS2812 solid red. | Force error state, verifikasi log. |
| `task_sm_verify_pin` | `bool task_sm_verify_pin(const char* pin, bool* verified_online)` | Verifikasi PIN: cek Firebase dulu (jika online), fallback ke NVS. Return `true` jika valid. Set `verified_online` flag. | Test dengan PIN valid/invalid di NVS dan Firebase. |
| `task_sm_handle_remote_command` | `void task_sm_handle_remote_command(RemoteCommand cmd)` | Process remote command dari CommandQueue. | Kirim command, verifikasi aksi. |

---

### [NEW] [task_media.h](file:///c:/Users/rafae/Forgor/ForgorEmbedded/PlatformIO/Square-SmartParcelBox/src/tasks/task_media.h) / [task_media.cpp](file:///c:/Users/rafae/Forgor/ForgorEmbedded/PlatformIO/Square-SmartParcelBox/src/tasks/task_media.cpp)

**Priority 1 (Low), Core 1.** SPI: MicroSD + Camera + Flash.

**Fungsi yang harus dibuat:**

| Fungsi | Signature | Deskripsi | Cara Uji |
|---|---|---|---|
| `task_media_entry` | `void task_media_entry(void* pvParameters)` | FreeRTOS task entry point. Menunggu notifikasi dari Task_StateMachine untuk aksi media. | Jalankan, kirim notifikasi, verifikasi aksi. |
| `task_media_start_recording` | `void task_media_start_recording(const char* timestamp)` | Mulai recording MJPEG: set camera ke VGA, capture frames terus-menerus, tulis ke SD (dengan SD_Mutex). | Panggil, verifikasi file .mjpeg dibuat. |
| `task_media_stop_recording` | `void task_media_stop_recording()` | Stop recording, finalize file MJPEG. | Stop, verifikasi file valid. |
| `task_media_capture_photo` | `bool task_media_capture_photo(const char* timestamp)` | Flash ON, wait 1000ms, set camera UXGA, capture, flash OFF, save ke SD (dengan SD_Mutex). Push ke upload queue. Sesuai CVL-004, CVL-005, CVL-006. Return `true` jika berhasil. | Panggil, verifikasi file .jpg dibuat dan ada di queue. |
| `task_media_capture_ondemand_photo` | `bool task_media_capture_ondemand_photo(const char* timestamp)` | Sama seperti `capture_photo` tapi push ke **front** of queue (NCC-005). | Panggil, verifikasi file di front queue. |
| `task_media_is_recording` | `bool task_media_is_recording()` | Return `true` jika sedang merekam video. | Cek saat record/tidak. |

---

### [NEW] [task_network.h](file:///c:/Users/rafae/Forgor/ForgorEmbedded/PlatformIO/Square-SmartParcelBox/src/tasks/task_network.h) / [task_network.cpp](file:///c:/Users/rafae/Forgor/ForgorEmbedded/PlatformIO/Square-SmartParcelBox/src/tasks/task_network.cpp)

**Priority 2, Core 0.** Wi-Fi + Firebase + Upload queue processor.

**Fungsi yang harus dibuat:**

| Fungsi | Signature | Deskripsi | Cara Uji |
|---|---|---|---|
| `task_network_entry` | `void task_network_entry(void* pvParameters)` | FreeRTOS task entry point. Loop: process RTDBQueue, process upload queue, maintain stream, heartbeat. | Jalankan, verifikasi heartbeat di Firebase. |
| `task_network_wifi_init` | `bool task_network_wifi_init()` | Inisialisasi Wi-Fi module (SFS-006). Log MAC address (DBG-009). Return `true`/`false`. | Panggil, cek log dan koneksi. |
| `task_network_wifi_connect` | `bool task_network_wifi_connect()` | Connect ke Wi-Fi dengan retry (max 25 attempts, 300ms interval). Log progress. Return `true`/`false`. | Panggil, cek koneksi. |
| `task_network_is_wifi_connected` | `bool task_network_is_wifi_connected()` | Return WiFi.status() == WL_CONNECTED. | Cek saat connected/disconnected. |
| `task_network_sync_ntp` | `bool task_network_sync_ntp()` | Sinkronisasi waktu via NTP (pool.ntp.org). Return `true`/`false`. | Panggil, print waktu saat ini. |
| `task_network_process_rtdb_queue` | `void task_network_process_rtdb_queue()` | Ambil item dari RTDBQueue, eksekusi write ke Firebase RTDB. | Enqueue item, verifikasi tertulis di Firebase. |
| `task_network_process_upload_queue` | `void task_network_process_upload_queue()` | Peek front of upload_queue.txt, upload file ke Firebase Storage (dengan SD_Mutex untuk baca file), update RTDB delivery log dengan URL, pop dari queue. Retry logic sesuai Section 4.3.8. | Tambah file ke queue, verifikasi upload dan URL update. |
| `task_network_get_timestamp` | `String task_network_get_timestamp()` | Return Unix timestamp saat ini sebagai string. | Print, verifikasi. |

---

## Fase 10 — Main Entry Point & Integration

---

### [MODIFY] [main.cpp](file:///c:/Users/rafae/Forgor/ForgorEmbedded/PlatformIO/Square-SmartParcelBox/src/main.cpp)

Entry point: inisialisasi semua hardware, buat RTOS primitif, buat semua tasks, jalankan STATE_START sequence.

**`setup()` flow:**

1. `Serial.begin(115200)` — init serial monitor
2. Print banner (Section 6.8.1)
3. `ws2812_init()` → set `WS2812_RED_BLUE_BLINK`
4. `Wire.begin(PIN_SDA, PIN_SCL)` — init I2C bus
5. Init semua HAL components (keypad, LED indicator, ToF, camera, SD card, NVS)
6. Log semua init results (Section 6.8.1)
7. Create RTOS IPC (queues, mutexes)
8. `task_network_wifi_init()` dan `task_network_wifi_connect()`
9. Handle connection results → update WS2812 pattern
10. Jika connected: `task_network_sync_ntp()`, `fb_rtdb_init()`, `fb_rtdb_create_device_entry()`
11. Determine initial state berdasarkan Section 6.6
12. Create all FreeRTOS tasks (`xTaskCreatePinnedToCore`)
13. Delete Arduino `loop()` task (optional, karena `loop()` bisa dibiarkan kosong)

**`loop()` flow:**

```cpp
void loop() {
    vTaskDelay(pdMS_TO_TICKS(1000)); // Tidak digunakan, semua logika di RTOS tasks
}
```

---

## Verification Plan

### Automated / Semi-Automated Tests

Setiap fase memiliki test yang bisa dijalankan di hardware nyata:

| Fase | Test Method | Cara Eksekusi |
|---|---|---|
| 0 | Kompilasi berhasil | `pio run` |
| 1 | Sketch test: panggil init + actuate, verifikasi via Serial + visual | Upload, monitor Serial |
| 2 | Sketch test: baca reed switch, print ke Serial | Buka/tutup pintu |
| 3 | Sketch test: scan keypad, display LED, baca ToF | Tekan tombol, letakkan objek |
| 4 | Sketch test: ambil foto, simpan ke SD, baca kembali | Monitor Serial + cek SD card |
| 5 | Sketch test: simpan/baca/hapus PIN di NVS | Monitor Serial |
| 6 | Unit test: coba semua transisi state (valid & invalid) | Monitor Serial |
| 7 | Integration test: koneksi Firebase, CRUD operations | Monitor Serial + Firebase Console |
| 8 | Sketch test: create/send/receive queue items | Monitor Serial |
| 9 | Integration test: jalankan semua tasks, test full flow | Monitor Serial + Firebase Console + hardware |
| 10 | Full system test: end-to-end package delivery flow | Monitor Serial + Firebase Console + mobile app |

### Manual Verification

- Verifikasi LED patterns secara visual di setiap fase
- Verifikasi Firebase Console untuk data yang di-upload
- Verifikasi foto dan video di SD card
- End-to-end test: masukkan PIN → buka pintu → masukkan paket → tutup pintu → cek notifikasi

---

## Summary Urutan Implementasi

```mermaid
graph TD
    F0["Fase 0: pins.h, config.h, credentials.h"]
    F1["Fase 1: HAL Output (WS2812, Relay, Flash LED)"]
    F2["Fase 2: HAL Input (Reed Switch)"]
    F3["Fase 3: HAL I2C (Keypad, LED Indicator, ToF)"]
    F4["Fase 4: HAL Complex (Camera, SD Card)"]
    F5["Fase 5: HAL NVS"]
    F6["Fase 6: State Machine"]
    F7["Fase 7: Firebase (RTDB, Storage)"]
    F8["Fase 8: RTOS IPC (Queues, Mutexes)"]
    F9["Fase 9: RTOS Tasks"]
    F10["Fase 10: main.cpp Integration"]

    F0 --> F1
    F0 --> F2
    F1 --> F3
    F2 --> F3
    F3 --> F4
    F4 --> F5
    F5 --> F6
    F5 --> F7
    F6 --> F8
    F7 --> F8
    F8 --> F9
    F9 --> F10
```

> [!TIP]
> Fase 1, 2, dan 3 bisa dikerjakan secara paralel karena tidak saling bergantung (hanya bergantung pada Fase 0). Fase 6 dan 7 juga bisa paralel.

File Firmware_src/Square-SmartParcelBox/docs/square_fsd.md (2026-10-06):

# Smart Parcel Box \- Functional Specification Document

## Document Information

| Field | Value |
| :---- | :---- |
| Version | 1.13 |
| Status | Draft |
| Created | 2026-02-25 |
| Updated | 2026-07-28 |

## 1\. Overview

### 1.1 Purpose

Square is an Internet of Things (IoT)-based smart parcel box system designed to address security issues in last-mile delivery logistics. The main purpose of this system is to prevent porch piracy and minimize unverified package issues (e.g., packages claimed to have been delivered but no physical evidence at the location).

Square solves these problems by transforming passive storage boxes into active safes that require courier authentication via a 4-digit limited-use PIN, the use of which can be customized by the owner. Additionally, the system provides peace of mind to owners by providing box capacity reports and authentic visual evidence (a photo of the package) sent directly to the owner's phone every time the door is closed.

### 1.2 System Context

The Square system operates through a sequential workflow that connects physical interactions in the field with data processing in the cloud and user applications. The system's main operational flow is as follows:

A. Package Receiving Flow (Courier to Square)

- **Courier Authentication:** The courier sees the 4-digit limited-use PIN printed on the delivery note and enters it via the 3x4 Matrix Keypad. After each 4-digit PIN entry, the system automatically verifies the PIN. Furthermore, after each incorrect 4-digit PIN entry, the system automatically resets the PIN to allow the courier to enter again. The system also provides visual feedback in the form of 4 LED indicators that illuminate according to the number of digits entered.  
- **Door Access:** The system validates the PIN. If correct, the Solenoid Lock will open. When the door is pulled, the Magnetic Reed Switch will release (move away), and the system will immediately start recording an MJPEG video to the MicroSD Card.  
- **Data Recording (Trigger Event):** After the courier places the package and closes the door again, the Reed Switch will be re-engaged. As soon as the door is closed, the system will capture the time data as a package receipt log timestamp, stop the MJPEG video recording, take a photo using the OV2640 camera, read the remaining distance using the ToF (Time-of-Flight) sensor, create a receipt entry in the Firebase Realtime Database and upload the photo evidence to Firebase Cloud Storage using the previously obtained timestamp as the photo evidence name.  
- **Capacity Logic (ToF Sensor):** The ToF sensor compares the distance read with the preset number (maximum width limit of the box). If the reflection distance is less than the preset number, the system detects an “Overload” status, indicating that the parcel must be emptied immediately.  
- **Local Storage & Transmission (Failsafe Mechanism):** To prevent data loss due to unstable internet connections, photos will first be stored on the local SD Card on the ESP32-S3. Once safely stored, the data will be uploaded to Firebase Cloud Storage via Wi-Fi to update the status.

B. User Application Features (Square App to User)

The Square mobile application acts as the main control center for homeowners, with the following functional features:

- **Visual History Log:** Users can view a gallery of all photos of packages that have been picked up, complete with timestamps (time and date of event).  
- **Remote Control:** Users can remotely unlock and lock the Solenoid Lock without needing to enter a PIN.  
- **PIN Generator with Usage Limits:** A feature to generate limited-use PIN that users can copy to their shipping notes when shopping online.  
- **Capacity Status (ToF Indicator):** Displays the status of the ToF sensor. If the preset threshold is exceeded, the application will provide a visual warning that the box is full/overloaded and must be emptied.  
- **On-Demand Snapshot:** A special button on the application that allows users to command the ESP32-S3 to take real-time photos of the conditions inside the Square whenever needed.  
- **Video On-Demand Request:** A special button on the application that allows users to command the ESP32-S3 to upload specific MJPEG video of the package insertion process to Firebase and retrieve the video to the user application.

## 2\. Hardware Architecture & Pin Mapping

### 2.1 Target Platform

| Main Components | Specifications / Type | Functional Role in the System |
| :---- | :---- | :---- |
| **Microcontroller Unit (MCU)** | ESP32-S3 (WROOM) N16R8 | Acts as a control center (state machine), processes Wi-Fi connections, and manages the camera's frame buffer using PSRAM. |
| **I/O Expander (Keypad)** | PCF8574 I/O Expander at address 0x20 | As an I/O Expander for 3x4 Matrix Keypad  |
| **I/O Expander (LED)** | PCF8574 I/O Expander at address 0x21 | As an I/O Expander for 4x 5mm LED indicator |
| **Camera Module** | OV2640 (2 Megapixel) | Records video while the package is inserted and takes photos after the package is inserted. Initialized with UXGA resolution JPG format (1600x1200) for photos and VGA resolution MJPEG format (640x480) for videos. |
| **Auxiliary Flash LED** | 3W HPL LED \+ IRLZ44N Logic-level MOSFET \+ Current limiting Chalk Resistor | Provides stable additional lighting during shooting. Controlled via logic-level MOSFETs to ensure instant response and allow LED brightness to be adjusted. |
| **4x 5mm LED indicator \+ resistor**  | Blue 5mm LED \+ 220Ω Resistor | Serves as visual feedback for the courier when entering the PIN, showing how many digits have been inputted. |
| **Capacity Sensor** | Time-of-Flight (ToF) VL53L0X at address 0x29. | Installed horizontally on the inner side wall at a specific threshold height (38 cm from the base, just below the top drop-slot mechanism). It acts as an optical tripwire, shooting an infrared beam across the 40 cm width of the box to detect if the package stack has reached maximum capacity. |
| **Door Sensor** | Magnetic Reed Switch | Provides a digital input to detect the physical status of the door. If the door is closed, the reading is (`HIGH`). Conversely, if the door is open, the reading is (`LOW`). |
| **Door Actuator** | Solenoid Door Lock 12V \+ Relay Module (physically configured to High Level Trigger/Active HIGH mode) | Physical locking mechanism. Activate (`HIGH`) to disengage the lock and inactivate (`LOW`) to engage the lock. |
| **Power Supply** |  |  |
| **5 Volt Power Source** | LM2596 3A DC-DC step-down (buck) switching regulator module | Provides 5 Volt power for MCU, sensors and LED from 12 Volt power |
| **12 Volt Power Source** | 12V 3A DC adapter | Provides 12 Volt power for the entire system from 220V AC power source |

### 2.2 Pin Assignments

#### ESP32-S3 (WROOM) N16R8 GPIO

| Code Constant | GPIO | I/O Type | Description & Hardware Limitations |
| :---- | :---- | :---- | :---- |
| **Internal Actuators** |  |  |  |
| `PIN_LED_WS2812` | 48 | Output | System status indicators. The patterns are described in the table below. |
| **External Sensors & Actuators** |  |  |  |
| `PIN_RELAY_SOLENOID` | 14 | Output | Control signal to the Relay module. Active `HIGH`. MUST NOT be pulled from the strapping pin. |
| `PIN_AUX_FLASH` | 2 | Output | Control signal to the IRLZ44N base pin. Active `HIGH`. |
| `PIN_DOOR_SWITCH` | 1 | Input | Signal from the Reed Switch. MUST be set as `INPUT`. Door closed \= `HIGH`, open \= `LOW`. |
| `PIN_SDA` | 21 | I/O | I2C Data line for PCF8574 I/O Expander and VL53L0X ToF Sensor (daisy chain). |
| `PIN_SCL` | 47 | I/O | I2C Clock line for PCF8574 I/O Expander and VL53L0X ToF Sensor (daisy chain). |
| **Camera Module Interface (OV2640)** |  |  |  |
| `PIN_CAM_D0` | 11 | Input | Camera DVP Data Line 0 (Y2). |
| `PIN_CAM_D1` | 9 | Input | Camera DVP Data Line 1 (Y3). |
| `PIN_CAM_D2` | 8 | Input | Camera DVP Data Line 2 (Y4). |
| `PIN_CAM_D3` | 10 | Input | Camera DVP Data Line 3 (Y5). |
| `PIN_CAM_D4` | 12 | Input | Camera DVP Data Line 4 (Y6). |
| `PIN_CAM_D5` | 18 | Input | Camera DVP Data Line 5 (Y7). |
| `PIN_CAM_D6` | 17 | Input | Camera DVP Data Line 6 (Y8). |
| `PIN_CAM_D7` | 16 | Input | Camera DVP Data Line 7 (Y9). |
| `PIN_CAM_XCLK` | 15 | Output | System Clock from ESP32-S3 to Camera (usually 20MHz). |
| `PIN_CAM_PCLK` | 13 | Input | Pixel Clock from Camera to ESP32-S3. |
| `PIN_CAM_VSYNC` | 6 | Input | Vertical Sync (marker for new frame). |
| `PIN_CAM_HREF` | 7 | Input | Horizontal Reference (marker for valid pixel line). |
| `PIN_CAM_SIOD` | 4 | I/O | SCCB Data Line for OV2640 register configuration. |
| `PIN_CAM_SIOC` | 5 | Output | SCCB Clock Line for OV2640 register configuration. |
| **MicroSD Card** |  |  |  |
| `PIN_SD_DATA` | 40 | I/O | SD Data line (1-bit mode). Connected internally |
| `PIN_SD_CLK` | 39 | Output | SD Clock line. Connected internally |
| `PIN_SD_CMD` | 38 | I/O | SD Command line. Connected internally |

#### PCF8574 I/O Expander (Address: 0x20)

| Code Constant | Pin | I/O Type | Description & Hardware Limitations |
| :---- | :---- | :---- | :---- |
| **3x4 Matrix Keypad** |  |  |  |
| `PIN_KYPD_R1` | P0 | Output | Keypad Row 1 (1, 2, 3). |
| `PIN_KYPD_R2` | P1 | Output | Keypad Row 2 (4, 5, 6). |
| `PIN_KYPD_R3` | P2 | Output | Keypad Row 3 (7, 8, 9). |
| `PIN_KYPD_R4` | P3 | Output | Keypad Row 4 (\*, 0, \#). |
| `PIN_KYPD_C1` | P4 | Input | Keypad Column 1 (1, 4, 7, \*). Acts as quasi-bidirectional input (Written `HIGH` to enable weak pull-up for reading). |
| `PIN_KYPD_C2` | P5 | Input | Keypad Column 2 (2, 5, 8, 0). Acts as quasi-bidirectional input (Written `HIGH` to enable weak pull-up for reading). |
| `PIN_KYPD_C3` | P6 | Input | Keypad Column 3 (3, 6, 9, \#). Acts as quasi-bidirectional input (Written `HIGH` to enable weak pull-up for reading). |

#### PCF8574 I/O Expander (Address: 0x21)

| Code Constant | Pin | I/O Type | Description & Hardware Limitations |
| :---- | :---- | :---- | :---- |
| **LED Indicator** |  |  |  |
| `PIN_KYPD_IND_0` | P0 | Output | First digit input indicator. Active `LOW`. |
| `PIN_KYPD_IND_1` | P1 | Output | Second digit input indicator. Active `LOW`. |
| `PIN_KYPD_IND_2` | P2 | Output | Third digit input indicator. Active `LOW`. |
| `PIN_KYPD_IND_3` | P3 | Output | Fourth digit input indicator. Active `LOW`. |

## 3\. Functional Requirements

### 3.1 Access Control

- **ACC-001**: System SHALL validate the limited use PIN entered by the courier using the keypad automatically on the 4th keystroke before opening the box.  
- **ACC-002**: System SHALL allow remote unlocking/locking of the solenoid lock via the Square mobile app.  
- **ACC-003**: System SHALL log every valid access attempt with a Unix timestamp.  
- **ACC-004**: System SHALL automatically reset the 4-digit input buffer if an incorrect PIN is entered.  
- **ACC-005**: System SHALL provide visual feedback using 4 LEDs to display the number of digits entered.  
- **ACC-006**: System SHALL add 1 amount of used quota (`used_quota`) to the PIN used by the courier in NVS and Firebase Realtime Database after the package receipt log timestamp is obtained.  
- **ACC-007**: System SHALL delete 4-digit PIN entries in NVS and Firebase Realtime Database where all quota has been used.  
- **ACC-008**: System SHALL implement an edge detection (debouncing) mechanism to ensure that physical keypad inputs are registered EXACTLY ONCE per valid keystroke.  
- **ACC-009**: System SHALL implements a custom keypad library to allow flexible mapping without relying on third-party keypad libraries.   
- **ACC-010**: System SHALL ignore keypress from key (`*`) and (`#`).

### 3.2 Camera & Visual Logging

- **CVL-001**: System SHALL take evidence using two methods, namely a video of the package insertion followed by a photo of the package receipt.  
- **CVL-002**: System SHALL start recording MJPEG video once the door reed switch detects the door is open and stop recording once the door reed switch detects the door is closed.  
- **CVL-003**: System SHALL save the recorded MJPEG video to the MicroSD Card, the system SHALL NOT upload the video without a request from the Square mobile app.  
- **CVL-004**: System SHALL take a JPG image using the OV2640 camera after the door is closed.  
- **CVL-005**: System SHALL save the captured JPG images to a MicroSD Card before uploading to the Firebase Cloud Storage platform.  
- **CVL-006**: System SHALL use the naming format (`img_1752587495.jpg`) for image capture and (`vid_1752587495.mjpeg`) for MJPEG video capture. Where `1752587495` is an example of a Unix timestamp taken at file creation.  
- **CVL-007**: System SHALL implement capacity threshold based Paired FIFO deletion of oldest visual evidence in SD Card. When the oldest video is deleted, its corresponding photo MUST also be deleted.  
- **CVL-008**: System SHALL implement capacity threshold based Paired FIFO deletion of oldest visual evidence in SD Card with threshold of remaining empty storage of 50MB. The system CAN delete more than one pair of oldest visual evidence UNTIL the remaining space is back at 50MB.  
- **CVL-009**: System SHALL initialize capacity threshold based Paired FIFO deletion of oldest visual evidence in SD Card at `STATE_IDLE` ONLY ONCE after the system goes into the state.  
- **CVL-010:** System SHALL NOT take pictures and record videos if a MicroSD Card is not available.  
- **CVL-011:** System SHALL NOT turn on flash if the camera initialization fails.  
- **CVL-012**: System SHALL NOT perform any picture taking and video recording if the camera initialization fails.  
- **CVL-013**: System SHALL NOT delete shipment entries in the Firebase Realtime Database.  
- **CVL-014**: System SHALL use the path `/users/user_uid/devices/mac_address/storage` to store photos and videos in Firebase Cloud Storage.  
- **CVL-015**: System SHALL do resolution change before the capture process is initiated (minimum delay is 400ms).

### 3.3 Notification & Connectivity

- **NCC-001**: System SHALL detect if the box storage is full using ToF (Time-of-Flight) sensor.  
- **NCC-002**: System SHALL update status when the storage is full (ToF sensor detects the distance below the threshold).  
- **NCC-003**: System SHALL send visual proof when the package arrives and the box is full.  
- **NCC-004**: System SHALL upload the video requested by the Square application in the `request_video_id` entry in the Firebase Realtime Database.  
- **NCC-005**: System SHALL prioritize video uploads requested by the Square mobile app on the upload queue `upload_queue.txt` on the MicroSD Card.  
- **NCC-006**: System SHALL use hardcoded credentials in the firmware to connect to Wi-Fi and Firebase. The required hardcoded credentials are listed in the table below.  
- **NCC-007**: System SHALL listen for data changes at `remote_sync` nodes to receive commands and sync pins ONLY when there are changes.  
- **NCC-008**: System SHALL implement heartbeat mechanism by updating unix timestamp on Firebase Realtime Database to monitor the device’s connectivity status at a fixed 30 seconds interval.  
- **NCC-009**: System SHALL ignore the used\_quota field value from the stream.

### 3.4 Hardcoded Credentials Definition

| Variable | Description |
| :---- | :---- |
| WIFI\_SSID | User's local Wi-Fi SSID. |
| WIFI\_PASSWORD | User's local Wi-Fi password. |
| FIREBASE\_DATABASE\_URL | Firebase Realtime Database URL (e.g., `project-id-default-rtdb.firebaseio.com`).  |
| FIREBASE\_WEBAPI\_KEY | Firebase Web API Key that is used to identify the Firebase project. |
| FIREBASE\_STORAGE\_BUCKET | Firebase Storage bucket location used to store uploaded .jpg and .mjpeg media. |
| DEVICE\_EMAIL | Dedicated Firebase Authentication email for this specific ESP32 hardware node. |
| DEVICE\_PASSWORD | Password for the dedicated hardware authentication account. |
| USER\_UID | The owner's Firebase Auth UID. Used for constructing the RTDB and Storage directory paths (e.g., `/users/{USER_UID}/...`).  |

## 4\. Network & Data Flow

### 4.1 Communication Protocol

| Data Type / Component | Communication Protocol | Port / Security | Functional Description |
| :---- | :---- | :---- | :---- |
| **Commands & Active Pins Sync (Firebase Realtime Database)** | Server-Sent Events (SSE) | Port 443 / TLS 1.2 | The ESP32-S3 maintains a persistent HTTP Keep-Alive connection (SSE) to listen for commands and PIN updates.  |
| **Status & Log Sync (Firebase Realtime Database)** | HTTPS | Port 443 / TLS 1.2 | The ESP32-S3 updates status and delivery logs using HTTP POST/PATCH for status updates and heartbeat. |
| **Visual Evidence (Storage)** | HTTPS | Port 443 / TLS 1.2 | Sending image (.jpg) and video (.mjpeg) files from a MicroSD Card to Firebase Cloud Storage using an HTTP POST Request. HTTPS was chosen because it is optimal for secure transfer of large data payloads. |
| **Local Buffering (SD Card)** | SPI Bus (Internal) | N/A (Hardware) | Serial peripheral interface protocol for offline writing of photo and video files to a MicroSD card with FAT32 file system format. |

### 4.2 Initial Connection Data Flow

1. **Credential Granting:** The Square system is programmed using the hardcoded credentials listed in the table below.  
2. **Power Connection:** The Square system is connected to a power supply, and all WS2812 indicators will alternately flash red and blue every 1 second.  
3. **Peripheral Initialization:** While the indicators remain flashing, the system initializes all components (keypad, camera, microSD, Wi-Fi, NVS, TOF, and indicator LEDs). The system then attempts to connect to Wi-Fi and Firebase, indicated by the input pin indicators flashing in an alternating pattern from left to right and right to left, alternating between LEDs every 250ms.  
4. **Connection to Wi-Fi and Firebase:** Once connected to Wi-Fi, the WS2812 indicators will glow solid blue. If the Wi-Fi connection fails, the WS2812 indicators will turn red. After successfully connecting to Wi-Fi, the next step is to sync to NTP server (pool.ntp.org). Then continue to connect to Firebase. If the connection to Firebase is successful, the WS2812 LED will turn green.  
5. **Creating an Entry in Firebase:** Using the UID information in the hardcoded credentials, the Square system MUST create a new device entry with its MAC address, along with its sub-entries (delivery logs, status, commands) and submit its heartbeat as last\_heartbeat.

### 4.3 Package Receipt Data Flow

1. **Authentication Request:** The courier enters a PIN via the 3x4 Matrix Keypad. If the input is 4 digits, the system verifies the code against the local cache (NVS).  
2. **Access Granted:** If the PIN is valid, the ESP32 triggers the Solenoid Relay (HIGH) to unlock the door.  
3. **Event Trigger:** The courier opens the door, and the reed switch detects the door status change to "Open." The system immediately starts MJPEG recording. No flash is triggered at this stage to prevent courier inconvenience.  
4. **System Activation:** The courier inserts the package and closes the door. The Reed Switch returns to the "Closed" status, the Solenoid Relay (Low) locks the door, and the system triggers the Post-Delivery Detection routine.  
5. **Visual Image Capture:** As soon as the door is locked, the packet reception log timestamp is captured, MJPEG recording is stopped, the recorded video is saved to the MicroSD Card (`vid_[timestamp].mjpeg`), and the MOSFET triggers the 3W LED flash to a continuous-on state. The OV2640 camera module waits for a 1000ms warm-up period (to stabilize the AWB/AEC), captures one high-resolution frame, and then the LED flash is turned off.  
6. **Local Buffering:** The image is saved to the MicroSD Card (`img_[timestamp].jpg`). The image file name is inserted into the upload queue upload\_queue.txt on the MicroSD Card.  
7. **Capacity Threshold Detection:** The Time-of-Flight (ToF) sensor measures the horizontal distance across a box (standard width \~40 cm). If the stack of packages reaches a height of 38 cm and breaks the ToF laser beam (readings \< 35 cm with a 5 cm error tolerance).  
8. **Cloud Sync:**  
- If Online: The system uploads logs to the Firebase Realtime Database and sends an HTTP POST (Photo) to Firebase Cloud Storage.  
- If Offline: The system retries with the following interval scheme: the first failure waits 5 minutes, the second failure and all subsequent failures wait 15 minutes per attempt.

### 4.4 On-Demand Snapshot Data Flow

1. **Command Reception:** The Square system receives a command to perform an On-Demand Snapshot with the timestamp provided by the Square mobile app. The Square system immediately prepares to take the image.  
2. **Visual Image Capture:** A MOSFET triggers the 3W LED flash to a continuous-on state. The OV2640 camera module waits for a 1000ms warm-up period (to stabilize the AWB/AEC), captures one high-resolution frame, and then the LED flash turns off.  
3. **Local Buffering & Queue Prioritization:** The image is stored on the MicroSD card (`img_[timestamp].jpg`). Then, the image file name is inserted at the front of the upload queue (`upload_queue.txt`) on the MicroSD Card. This prioritizes the user's on-demand snapshot request over standard background uploads.  
4. **Capacity Threshold Detection:** The Time-of-Flight (ToF) sensor measures the horizontal distance across a box (standard width \~40 cm). If the stack of packages reaches a height of 38 cm and breaks the ToF laser beam (readings \< 38 cm with a 2 cm error tolerance).  
5. **Cloud Synchronization:**  
- If Online: The system uploads the log to the Firebase Realtime Database and sends an HTTP POST (Photo) to Firebase Cloud Storage.  
- If Offline: The system cancels the log entry and deletes the captured photo.  
6. **Database Synchronization & Cleanup:** After a successful upload, the `request_photo_ondemand` becomes empty, the app detects this change and immediately accesses the delivery log and looks for an entry with the given timestamp. Then, the app accesses the image link and displays it to the user.

### 4.5 On-Demand Video Request Data Flow

1. **Video Request Command:** The user requests video evidence via the mobile app, which writes the target log's timestamp into the `request_video_id` field in the Firebase Realtime Database. The ESP32-S3 detects this command and prepares to retrieve the corresponding video (`vid_[timestamp].mjpeg`) from the MicroSD Card.  
2. **Queue Prioritization:** The requested video filename is inserted at the front of the upload queue (`upload_queue.txt`) on the MicroSD Card. This prioritizes the user's on-demand retrieval over standard background uploads.  
3. **Cloud Synchronization:**  
- If Online: The system retrieves the video file from the MicroSD Card and executes an HTTP POST request to upload the payload to Firebase Cloud Storage.  
- If Offline: The system immediately aborts the upload process and ignores the request to prevent massive queue blockages upon network reconnection.  
4. **Database Synchronization & Cleanup:** Upon successful upload, the ESP32-S3 updates the `video_evidence_url` field within the specific delivery log entry in the Firebase Realtime Database. Finally, the system resets the `request_video_id` command field to an empty string "" to signal completion and allow the mobile app to display the video.

## 5\. Cloud-Device Interface

### 5.1 Cloud-to-Device Commands 

### RTDB Path: devices/{mac\_address}/remote\_sync/commands

| JSON Key | Type | Action MUST be done by ESP32-S3 | Feedback |
| :---- | :---- | :---- | :---- |
| `request_video_id` | String | If string is not empty (filled with timestamp from mobile app): Start On-Demand Video Request flow. | After the video with the timestamp is uploaded, ESP-S3 MUST empty the `request_video_id` key value to "". |
| `unlock` | Boolean | If `true`: Activate Relay (`HIGH`) to disengage the solenoid lock. | After the relay is activated, ESP32-S3 MUST rewrite the value of `unlock` to `false`. |
| `lock` | Boolean | If `true`: Deactivate Relay (`LOW`) to engage the solenoid lock. | After the relay is deactivated, ESP32-S3  MUST rewrite the value of `lock` to `false`. |
| `request_photo_ondemand` | String | If string is not empty (filled with timestamp from mobile app): Start On-Demand Snapshot flow. | After the photo with the timestamp is uploaded, ESP-S3 MUST empty the `request_photo_ondemand` key value to "". |

**Conflict Resolution:** If both unlock and lock command fields are simultaneously true, the system SHALL prioritize the lock command to engage the solenoid (security-first principle). After executing, both fields MUST be reset to false.

### 5.2 Device-to-Cloud Status

### RTDB Path: devices/{mac\_address}/status

| JSON Key | Type | Condition | Value Definition |
| :---- | :---- | :---- | :---- |
| `last_heartbeat` | String | Refresh every 30 seconds with the key value of the current timestamp.  | `timestamp`: Unix timestamp in seconds of the current timestamp in ESP32. |
| `isOpen` | Boolean | Refreshed every time there are changes in Magnetic Reed Switch physical status. | `true`: The box door is opened. `false`: The box door is closed. |
| `isUnlocked` | Boolean | Refreshed every time there are changes in the logic status of `PIN_RELAY_SOLENOID` GPIO. | `true`: Solenoid active (unlocked). `false`: Solenoid deactivated (locked). |
| `isFull` | Boolean | Measured and sent 1 time right after the door closing and photo taking sequence is completed. | `true`: ToF distance \< 38 cm (Box is full). `false`: ToF distance ≥ 38 cm (Box is empty). |

## 6\. Non-Functional Requirements

### 6.1 Performance

- **PRF-001**: System SHALL execute solenoid lock response within 2 seconds of a valid PIN entry.   
- **PRF-002**: System SHALL send detection data from the device to arrive to the user's smartphone in no more than 5 seconds under stable network conditions.   
- **PRF-003**: System SHALL complete the transmission of visual evidence to the firebase within 20 seconds under stable network conditions.  
- **PRF-004**: System SHALL implement FreeRTOS for better utilization of CPU resources in handling tasks with diverse loads and preventing conflicts due to more than one hardware using the same communication protocol (e.g., I2C, SPI) simultaneously according to the given table.

### 6.2 Security/Fail-safe

- **SFS-001**: System SHALL implement a failsafe mechanism to keep the door closed (solenoid inactive) when disconnected from the power source.  
- **SFS-002**: System SHALL have the ability to authenticate PINs even when disconnected from Wi-Fi with valid PIN synchronization between Firebase Realtime Database and NVS.  
- **SFS-003**: System SHALL have the ability to capture visual evidence either images or videos even when disconnected from Wi-Fi.  
- **SFS-004**: System SHALL re-lock if within 10 seconds after the PIN is correct, the door is not opened by the courier.  
- **SFS-005**: System SHALL NOT send box fullness status if it is disconnected from firebase.  
- **SFS-006**: System SHALL limit Wi-Fi connection attempts to a maximum of 25 at a polling rate of 300ms. If this limit is reached, the connection is considered a failure, and the user must power cycle before reconnecting.  
- **SFS-007**: System SHALL continue with the system activation phase even if there is a failed hardware initialization.  
- **SFS-008**: System SHALL remain locked on any keypad input if there is no active pin stored and it is not connected to the Firebase Realtime Database.  
- **SFS-009**: System SHALL prevent Task Watchdog Timer (TWDT) timeouts by implementing a minimum non-blocking delay of 10ms using \`vTaskDelay(pdMS\_TO\_TICKS(10))\` to every continuous execution loop (e.g., \`while(1)\` or polling loops) within any FreeRTOS task.  
- **SFS-010**: System SHALL go into STATE\_ERROR if the system runs out of PIN quota AND is not connected to the Firebase.

### 6.3 Debugging

- **DBG-001**: System SHALL log every hardware connection and initialization to the serial monitor as specified at Debug Log Formatting.  
- **DBG-002**: System SHALL log network-related connection initialization to the serial monitor as specified at Debug Log Formatting.  
- **DBG-003**: System SHALL log every firebase process to the serial monitor as specified at Debug Log Formatting.  
- **DBG-004**: System SHALL log every change from sensor and hardware actions to the serial monitor as specified at Debug Log Formatting.  
- **DBG-005**: System SHALL implement well-commented code for easier debugging.  
- **DBG-006**: System SHALL implement a state machine to constrain the system's behavior to well-defined states, making it easier to isolate and debug unexpected transitions.  
- **DBG-007**: System SHALL implement the debug LED patterns in the table below.  
- **DBG-008**: System SHALL perform a dummy write-and-read verification on the MicroSD Card during the peripheral initialization phase and log the final status (PASSED/FAILED) to the serial monitor.   
- **DBG-009**: System SHALL NOT get and display the Wi-Fi module MAC Address in the serial monitor if Wi-Fi initialization fails.  
- **DBG-010**: System SHALL NOT get and display the type and size of MicroSD card if MicroSD card initialization fails.  
- **DBG-011**: System SHALL NOT get and display the number of active pins in NVS if NVS initialization fails..  
- **DBG-012**: System SHALL send fatal error logs at STATE\_ERROR every 1 second.

### 6.4 RTOS Tasks

| Name | Priority | Core | Hardware resources used by the task | Purpose |
| :---- | :---- | :---- | :---- | :---- |
| Task\_Network | 2 | 0 | Wi-Fi, SPI (MicroSD), NVS | Maintains the Wi-Fi connection, performs Firebase Realtime Database handshakes, reads incoming commands and data from Firebase, and processes photo/video uploads to Firebase Storage. |
| Task\_Keypad\_LED | 4 \- Highest | 1 | I2C (Keypad, LED Input Indicator) | Listens for key presses from the PCF8574 keypad I/O expander, records each digit input, and drives the LED indicators accordingly. |
| Task\_StateMachine  | 3 | 1 | Relay Solenoid, I2C (ToF Sensor), WS2812 RGB LED, Reed Switch, NVS | Manage state transitions, monitor all triggers that cause state changes, and coordinate overall system behavior.  |
| Task\_Media | 1 \- Low | 1 | SPI (MicroSD), Flash LED, OV2640 | Handles all media-related operations: recording MJPEG video and still images via the OV2640, controlling the auxiliary flash for photo capture, and writing media files to the MicroSD Card.  |

### 6.5 RTOS IPC (Inter-Process Communication)

| Name | Type | Purpose |
| :---- | :---- | :---- |
| RTDBQueue  | Queue | Queue for outgoing Firebase Realtime Database write operations. Ensures that status updates and log entries are sent sequentially without blocking other tasks. The queue depth is 10\. |
| CommandQueue | Queue (Enum) | Buffers incoming remote commands (e.g., unlock, take photo) parsed from Firebase RTDB stream by `Task_Network`. Ensures asynchronous and non-blocking command execution by the `Task_StateMachine`. The queue depth is 3\. |
| I2C\_Mutex | Mutex | Prevents simultaneous I2C bus access between all three I2C devices (keypad, LED indicator, and ToF sensor). Only one device can use the bus at a time. |
| SD\_Mutex | Mutex | Prevents simultaneous SPI bus access between Task\_Network and Task\_Media in accessing the MicroSD Card. |
| NVS\_Mutex | Mutex | Prevents simultaneous access when reading and modifying the active\_pins JSON string. |

### 6.6 Device States

| State | Trigger In | Trigger Out | Explanation |
| :---- | :---- | :---- | :---- |
| STATE\_START | Power ON or Hardware Reset. | To `STATE_IDLE`: Wi-Fi connected successfully with OR without other hardware problems (Except Wi-Fi) OR Wi-Fi failed AND valid PINs exist in NVS. To `STATE_ERROR`: Wi-Fi failed AND NVS `active_pins` is empty. | Initializes hardware components and WS2812 indicator. Attempts Wi-Fi/Firebase connection with limited attempt. Checks NVS for local active PINs. |
| STATE\_IDLE | Completion of `STATE_START`, `STATE_DELIVERY`, or `STATE_ONDEMAND`.  | To `STATE_DELIVERY`: A valid 4-digit PIN is entered via keypad. To `STATE_ONDEMAND`: `request_photo_ondemand` command received from Firebase Realtime Database. | Standby mode. The system actively listens for physical keypad input or remote Firebase commands without executing heavy tasks.  |
| STATE\_DELIVERY | Valid PIN successfully authenticated (locally or via cloud).  | To `STATE_IDLE`: Delivery sequence completed (media uploaded or queued) OR 10-second timeout triggered if the door is never opened after unlocking.  | Triggered after every 4-digit PIN input. Authenticates the PIN against the local NVS cache if offline, or against Firebase Realtime Database if online. Performs video recording, image capture, ToF measurement, uploads to `storage`, and writes to delivery logs. If it is correct and the door is still closed after 10 seconds, it returns to idle state. |
| STATE\_ONDEMAND | `request_photo_ondemand` command set to request `timestamp` in Firebase Realtime Database.  | To `STATE_IDLE`: Capture and upload sequence completed, and Firebase Realtime Database command is reset to "".  | Performs an on-demand visual capture without unlocking the door. Takes a photo, measures ToF, uploads to `storage`, and writes to delivery logs.  |
| STATE\_ERROR | From `STATE_START`: Total offline isolation (Wi-Fi failed AND (empty NVS OR Failed NVS)).  From `STATE_IDLE/DELIVERY`: The remaining quota in NVS is used up (0) AND the system is disconnected from Firebase. | None (Dead state). Requires physical power cycle / hard reset by the user.  | Halts all actuator and sensor operations. WS2812 LED turns solid red. Sends a fatal error log every 1 second. |

### 6.7 Debug LED Patterns

| System Condition | WS2812 RGB LED | 4-digit password LED indicator  |
| :---- | :---- | :---- |
| The system is powered up and is initializing the hardware. | Red blue blink every 1 second | All OFF |
| The system has finished initiating the Wi-Fi and is trying to connect. | Red blue blink every 1 second | The flashing pattern alternates from left to right and right to left, alternating between LEDs every 250ms. |
| The system is successfully connected to Wi-Fi. | Solid blue | All OFF |
| The system (failed to connect to Wi-Fi OR Wi-Fi initialization failed OR failed to connect to Firebase) AND ( NVS has NO active pins OR NVS FAILED to initialize). | Solid red | All OFF |
| The system (failed to connect to Wi-Fi OR Wi-Fi initialization failed OR failed to connect to Firebase) AND NVS HAS active pins. | Solid purple | All OFF (Waiting for pin insertion) |
| The system is successfully connected to Firebase and there are no hardware initialization issues. | Solid green | All OFF (Waiting for pin insertion) |
| The system successfully connected to Firebase but there was a hardware initialization issue (except Wi-Fi). | Solid yellow | All OFF (Waiting for pin insertion) |

### 6.8 Debug Log Formatting Examples

#### 6.8.1 Startup and non network-related hardware initialization (STATE\_START)

**Scenario:**   
Non network-related hardware initialization: SUCCESS  
\`\`\`  
\[INFO\] \[SYSTEM\] \=============================================  
\[INFO\] \[SYSTEM\] Square \- Smart Parcel Box by REN  
\[INFO\] \[SYSTEM\] \=============================================  
\[INFO\] \[SYSTEM\] Starting up. WS2812 pattern: RED-BLUE-BLINK  
\[INFO\] \[HARDWARE\] Init Keypad PCF8574 at 0x20: SUCCESS (or FAILED)  
\[INFO\] \[HARDWARE\] Init LED PCF8574 at 0x21: SUCCESS (or FAILED)  
\[INFO\] \[HARDWARE\] Init ToF VL53L0X at 0x29: SUCCESS (or FAILED)  
\[INFO\] \[HARDWARE\] Init OV2640 Camera: SUCCESS (or FAILED)  
\[INFO\] \[NVS\] Init NVS: SUCCESS (or FAILED). Found 3 active pins. (or 0 active pins)  
\[INFO\] \[SD\_CARD\] Init MicroSD: SUCCESS (or FAILED). Type: SDHC, Size: 7284 MB.  
\[INFO\] \[SD\_CARD\] Performing write test: PASSED (or FAILED)  
\`\`\`

#### 6.8.2 Network-related hardware initialization and connection (STATE\_START)

**Scenario:**   
Non network-related hardware initialization: SUCCESS  
Wi-Fi initialization SUCCESS AND Wi-Fi Connection SUCCESS AND Firebase connection SUCCESS  
\`\`\`  
\[INFO\] \[WIFI\] Init Wi-Fi module: SUCCESS (or FAILED). MAC: A1:B2:C3:D4:E5:F6  
\[INFO\] \[SYSTEM\] LED Expander alternating pattern: ON  
\[INFO\] \[WIFI\] Connecting to My\_WiFi\_SSID (1/25)...  
\[INFO\] \[WIFI\] Connecting to My\_WiFi\_SSID (2/25)...  
\[SUCCESS\] \[WIFI\] Connected. IP: 192.168.1.168  
\[INFO\] \[SYSTEM\] LED Expander alternating pattern: OFF  
\[INFO\] \[SYSTEM\] WS2812 pattern: SOLID\_BLUE  
\[INFO\] \[SYSTEM\] Syncing NTP pool.ntp.org: SUCCESS  
\[INFO\] \[FIREBASE\] Authenticating...  
\[SUCCESS\] \[FIREBASE\] Connected to Firebase.   
\[INFO\] \[SYSTEM\] WS2812 Set to: SOLID\_GREEN.   
\[INFO\] \[SYSTEM\] Initialization completed. \-\> \[STATE\_IDLE\]  
\`\`\`  
**Scenario:**   
Non network-related hardware initialization: PARTIAL  
Wi-Fi initialization SUCCESS AND Wi-Fi Connection SUCCESS AND Firebase connection SUCCESS

\`\`\`  
\[INFO\] \[WIFI\] Init Wi-Fi module: SUCCESS. MAC: A1:B2:C3:D4:E5:F6  
\[INFO\] \[SYSTEM\] LED Expander alternating pattern: ON  
\[INFO\] \[WIFI\] Connecting to My\_WiFi\_SSID (1/25)...  
\[INFO\] \[WIFI\] Connecting to My\_WiFi\_SSID (2/25)...  
\[SUCCESS\] \[WIFI\] Connected. IP: 192.168.1.168  
\[INFO\] \[SYSTEM\] LED Expander alternating pattern: OFF  
\[INFO\] \[SYSTEM\] WS2812 pattern: SOLID\_BLUE  
\[INFO\] \[SYSTEM\] Syncing NTP pool.ntp.org: SUCCESS  
\[INFO\] \[FIREBASE\] Authenticating...  
\[SUCCESS\] \[FIREBASE\] Connected to Firebase.   
\[INFO\] \[SYSTEM\] WS2812 Set to: SOLID\_YELLOW.   
\[INFO\] \[SYSTEM\] Initialization completed with warnings. \-\> \[STATE\_IDLE\]  
\`\`\`  
**Scenario:**   
Non network-related hardware initialization: SUCCESS OR PARTIAL  
Wi-Fi initialization FAILED OR Wi-Fi Connection FAILED OR Firebase connection FAILED  
NVS HAS active pins  
\`\`\`  
\[INFO\] \[SYSTEM\] LED Expander alternating pattern: ON  
\[INFO\] \[WIFI\] Connecting to My\_WiFi\_SSID (1/25)...  
.  
.  
.  
\[INFO\] \[WIFI\] Connecting to My\_WiFi\_SSID (25/25)... FAILED.  
\[INFO\] \[SYSTEM\] LED Expander alternating pattern: OFF  
\[WARN\] \[FIREBASE\] Network unavailable. Skipping authentication.  
\[INFO\] \[NVS\] Checking active pins... Found 3 active pins. There's still hope\!  
\[WARN\] \[SYSTEM\] Entering Offline Mode. WS2812 Set to: SOLID\_PURPLE.   
\[INFO\] \[SYSTEM\] Initialization completed with warnings. \-\> \[STATE\_IDLE\]  
\`\`\`  
**Scenario:**   
Non network-related hardware initialization: SUCCESS OR PARTIAL  
Wi-Fi initialization FAILED OR Wi-Fi Connection FAILED OR Firebase connection FAILED  
NVS HAS NO active pins OR NVS FAILED to initialize.  
\`\`\`  
\[INFO\] \[SYSTEM\] LED Expander alternating pattern: ON  
\[INFO\] \[WIFI\] Connecting to My\_WiFi\_SSID (1/25)...  
.  
.  
.  
\[INFO\] \[WIFI\] Connecting to My\_WiFi\_SSID (25/25)... FAILED.  
\[INFO\] \[SYSTEM\] LED Expander alternating pattern: OFF  
\[WARN\] \[FIREBASE\] Network unavailable. Skipping authentication.  
\[INFO\] \[NVS\] Checking active pins... 0 active pins found.  
\[ERROR\] \[SYSTEM\] No network and no active pins\! System isolated.  
\[ERROR\] \[SYSTEM\] WS2812 Set to: SOLID\_RED.  
\[INFO\] \[SYSTEM\] Halting operations. \-\> \[STATE\_ERROR\]

\`\`\`

#### 6.8.3 System Background Maintenance (STATE\_IDLE)

\`\`\`  
\[WARN\] \[SD\_CARD\] Space \< 50MB. Performing Paired FIFO...  
\[SUCCESS\] \[SD\_CARD\] Deleted pair 1752587495\.  
\[INFO\] \[FIREBASE\] Sending heartbeat (1752597477)... SUCCESS  
\[ERROR\] \[FIREBASE\] Sending heartbeat (1752597477)... FAILED  
\[INFO\] \[FIREBASE\] New active pins detected (2026) with quota 3  
\[INFO\] \[NVS\] Active pins (2026) saved to NVS\!  
\[INFO\] \[FIREBASE\]   
\`\`\`

#### 6.8.4 Courier Authentication (STATE\_IDLE)

\`\`\`  
\[INFO\] \[KEYPAD\] Key pressed: 1  
\[INFO\] \[KEYPAD\] Key pressed: 5  
\[INFO\] \[KEYPAD\] Key pressed: 5  
\[INFO\] \[KEYPAD\] Key pressed: 4  
\[INFO\] \[KEYPAD\] Courier input buffer complete: 1554  
\[INFO\] \[FIREBASE\] Verifying PIN with Firebase...  
\[WARN\] \[FIREBASE\] Incorrect PIN. Resetting buffer.  
\[INFO\] \[NVS\] Verifying PIN 2026 with NVS (Offline mode)...  
\[SUCCESS\] \[NVS\] PIN 2026 is correct\!   
\[INFO\] \[SYSTEM\] Transitioning \-\> \[STATE\_DELIVERY\]  
\`\`\`

#### 6.8.5 Delivery Flow & Evidence Recording (STATE\_DELIVERY)

\`\`\`  
\[INFO\] \[DOOR\] Solenoid unlocked.   
\[INFO\] \[FIREBASE\] Status isUnlocked updated to true.   
Waiting for the courier (10s timeout)...  
\[INFO\] \[DOOR\] Reed switch: OPEN.   
\[INFO\] \[FIREBASE\] Status isOpen updated to true.   
\[INFO\] \[DOOR\] Starting video capture...  
\[INFO\] \[DOOR\] Reed switch: CLOSED.   
\[INFO\] \[FIREBASE\] Status isOpen updated to false.  
Timestamp: 1752587495\. Solenoid locked.  
\[INFO\] \[FIREBASE\] Status isUnlocked updated to false.  
\[INFO\] \[NVS\] PIN 2026 used\_quota incremented.  
\[INFO\] \[FIREBASE\] PIN 2026 used\_quota incremented.  
\[INFO\] \[CAMERA\] Stopping video. Saved to: vid\_1752587495.mjpeg  
\[INFO\] \[CAMERA\] Flash ON. Capturing photos...   
\[SUCCESS\] \[CAMERA\] Photo saved to: img\_1752587495.jpg. Flash OFF.  
\[INFO\] \[SD\_CARD\] Pushing img\_1752587495.jpg to upload\_queue.txt  
\[INFO\] \[TOF\] Distance: 39 cm. isFull: false (Threshold: \<38cm)  
\[INFO\] \[FIREBASE\] Status isFull updated to false.  
\[INFO\] \[FIREBASE\] Adding new delivery logs entry...  
\[SUCCESS\] \[FIREBASE\] Delivery logs entry added  
\[INFO\] \[SYSTEM\] Delivery sequence complete. \-\> \[STATE\_IDLE\]  
\`\`\`

#### 6.8.6 On-Demand Request

**Scenario:**  
SUCCESSFUL.  
\`\`\`  
\[INFO\] \[FIREBASE\] On-demand video request received for timestamp: 1752587495  
\[INFO\] \[SD\_CARD\] Pushing vid\_1752587495.mjpeg to front of upload\_queue.txt  
\[INFO\] \[FIREBASE\] Uploading vid\_1752587495.mjpeg...  
\[SUCCESS\] \[FIREBASE\] vid\_1752587495.mjpeg uploaded successfully.  
\[INFO\] \[FIREBASE\] Updating video\_evidence\_url in RTDB.  
\[INFO\] \[FIREBASE\] Request satisfied.

\[INFO\] \[FIREBASE\] On-demand snapshot request received\! Timestamp: 1752587598  
\[INFO\] \[SYSTEM\] Transitioning \-\> \[STATE\_ONDEMAND\]  
\[INFO\] \[CAMERA\] Flash ON. Capturing photo...   
\[SUCCESS\] \[CAMERA\] Photo saved: img\_1752587598.jpg. Flash OFF.  
\[INFO\] \[SD\_CARD\] Pushing img\_1752587598.jpg to front of upload\_queue.txt  
\[INFO\] \[TOF\] Distance: 15 cm. isFull: true  
\[INFO\] \[FIREBASE\] Status isFull updated to true.  
\[INFO\] \[FIREBASE\] Uploading snapshot logs...   
\[SUCCESS\] \[FIREBASE\] Snapshot logs successfully uploaded.   
\[INFO\] \[SYSTEM\] Snapshot sequence complete. \-\> \[STATE\_IDLE\]  
\`\`\`  
**Scenario:**  
FAILED.  
\`\`\`  
\[INFO\] \[FIREBASE\] On-demand video request received for timestamp: 1752587495  
\[INFO\] \[SD\_CARD\] Pushing vid\_1752587495.mjpeg to front of upload\_queue.txt  
\[INFO\] \[FIREBASE\] Uploading vid\_1752587495.mjpeg...  
\[ERROR\] \[FIREBASE\] vid\_1752587495.mjpeg failed to upload. Aborting…  
\[INFO\] \[SD\_CARD\] Deleting vid\_1752587495.mjpeg from upload\_queue.txt  
\[ERROR\] \[FIREBASE\] Request not satisfied\!

\[INFO\] \[FIREBASE\] On-demand snapshot request received\! Timestamp: 1752587598  
\[INFO\] \[SYSTEM\] Transitioning \-\> \[STATE\_ONDEMAND\]  
\[ERROR\] \[CAMERA\] Camera failed\! No video and photo capture\!  
\[ERROR\] \[SD\_CARD\] MicroSD failed\! No video and photo capture\!   
\[ERROR\] \[SYSTEM\] Snapshot sequence aborted. \-\> \[STATE\_IDLE\]  
\`\`\`

#### 6.8.7 Remote Lock Control

\`\`\`  
\[INFO\] \[FIREBASE\] Door unlock command received\!  
\[INFO\] \[DOOR\] Solenoid unlocked.   
\[INFO\] \[FIREBASE\] Status isUnlocked updated to true.   
\[INFO\] \[FIREBASE\] Clearing unlock command… Command satisfied

\[INFO\] \[FIREBASE\] Door lock request received\!  
\[INFO\] \[DOOR\] Solenoid locked.   
\[INFO\] \[FIREBASE\] Status isUnlocked updated to false.   
\[INFO\] \[FIREBASE\] Clearing lock command… Command satisfied

\[ERROR\] \[FIREBASE\] Door lock and unlock request received simultaneously\!  
\[INFO\] \[DOOR\] Solenoid locked.   
\[INFO\] \[FIREBASE\] Status isUnlocked updated to false.   
\[INFO\] \[FIREBASE\] Clearing lock and unlock command… Failsafe approach  
\`\`\`

#### 6.8.8 Fatal Error (STATE\_ERROR)

\`\`\`  
\[ERROR\] \[SYSTEM\] Fatal error occurred\! No local active pins, no connection to Firebase. Please power cycle.   
\[ERROR\] \[SYSTEM\] Fatal error occurred\! No local active pins, no connection to Firebase. Please power cycle.  
\`\`\`

## 7\. Data Schema & Storage Architecture

### 7.1 Firebase Realtime Database JSON Tree

\`\`\`json  
{  
"users": {  
    "user\_uid": {  
        "username": "benson.dunwoody",  
        "devices": {  
            "25d57a9eba89": {  
                "delivery\_logs": {  
                    "1752587495": {  
                        "used\_pin": "4584",  
                        "event\_type": "PackageInsertion",  
                        "photo\_evidence\_url": "firebase\_storage\_url\_for\_img\_1752587495.jpg",  
                        "video\_evidence\_url": "firebase\_storage\_url\_for\_vid\_1752587495.mjpeg"  
                    },  
                    "1752587598": {  
                    "used\_pin": "",  
                    "event\_type": "OnDemandSnapshot",  
                    "photo\_evidence\_url": "firebase\_storage\_url\_for\_img\_1752587598.jpg"  
                    }  
                },  
                "device\_name": "mySquare",  
                "remote\_sync": {  
                    "active\_pins": {  
                        "4584": {  
                            "quota": 5,  
                            "used\_quota": 1  
                        }  
                    },  
                    "commands": {  
                        "request\_video\_id": "",  
                        "unlock": false,  
                        "lock": false,  
                        "request\_photo\_ondemand": ""  
                    }  
                },  
                "status": {  
                    "last\_heartbeat": "1752597477",  
                    "isFull": false,  
                    "isOpen": false,  
                    "isUnlocked": false  
                }  
            }  
        }  
    }  
  }  
}  
\`\`\`  
**Structure Purpose:**

- **users/**: Contains all authenticated user entries. Each entry has a name with a UID from Firebase Authentication.  
- **user\_uid/**: Contains user profile data, including username (using local part of email address e.g, benson.dunwoody if the email used for user registration in mobile app is benson.dunwoody@gmail.com), and connected devices.  
- **devices/**: Contains all of the user's Square Box entries. Each entry is named using the device's 12-digit hexadecimal MAC address.   
- **25d57a9eba89/**: Example of a paired Square device entry. Contains active PIN, device name, shipping log, status, and commands.  
- **delivery\_logs/**: Contains all packet reception and on-demand snapshot log entries for this device. Each entry is named based on a Unix timestamp (the timestamp is based on the time the door closed after the packet was inserted, or the time the application triggered the on-demand snapshot).  
- **remote\_sync/**: Encapsulate entries that are streamed to the paired Square device every time there is a change.   
- **active\_pins/**: Contains active PINs for the device. Each entry stores the total quota and the number of times the PIN has been used.   
- **commands/**: Contains fields used by the mobile app to interact with Square remotely, including requesting video uploads, locking or unlocking the solenoid, and triggering manual photo capture.  
- **status/**: Contains the real-time status of the Square box, which is used by the mobile app to display: connection status to Firebase Realtime Database (determined by the mobile app by calculating the delta between last\_heartbeat and the current time), box fullness level (ToF based), door open status (reed switch) and locked status (relay).  
- **1752587495/**: Example delivery log entry. The key is the Unix timestamp of the door closing after the package was inserted (or the time of a manual trigger). This entry contains the URL of the photo and video evidence, the PIN used to authorize access (blank if manually triggered), and the event type (`OnDemandSnapshot` or `PackageInsertion`).

### 7.2 Firebase Storage Schema

\`\`\`  
/  
└── users/  
    └── {user\_uid}/  
        ├── profile.jpg  
        └── devices/  
            └── {12\_digit\_mac\_address\_hex}/  
                └── storage/  
                    ├── 1752587495/  
                     |    ├── img\_1752587495.jpg  
                     |    └── vid\_1752587495.mjpeg  
                    └── 1752587598/  
                          └── img\_1752587598.jpg  
\`\`\`  
**Folder Purpose:**

- **storage/**: The primary storage for all newly uploaded media. All new delivery media and on-demand snapshots are uploaded here by default.  
- **1752587495/**: An example of a delivery media folder with a packet insertion video (the user requested the video from the app), 1752587495, is a folder named after the Unix timestamp of the packet capture, measured when the door was closed again. Or during manual triggering, measured at the time of the request in the app.  
- **1752587598/**: An example of a delivery media folder without a packet insertion video (either the user has never requested a video from the application or it is an entry from a manual trigger), 1752587598 is a folder named based on the Unix timestamp of the packet capture, measured when the door is closed again. Or during manual triggering, measured at the time of the request in the app.

### 7.3 MicroSD Card Directory

\`\`\`  
/  
├── upload\_queue.txt  
├── 1752587495/  
│   ├── img\_1752587495.jpg  
│   └── vid\_1752587495.mjpeg  
└── 1752587598/  
     └── img\_1752587598.jpg  
\`\`\`  
**Purpose:**

- **upload\_queue.txt**: This is a file containing a queue for file uploads. When a new photo or video arrives from a packet, the photo's file name is added to the queue. The ESP32 then reads the queue and uploads it to Firebase. Once the upload is complete, the file name is removed from the queue. For user-requested photos or photos requested via on-demand snapshots, the file name is also added to the queue. If there is currently a queue, the user's request will be first in line (to be uploaded first).  
- **1752587495/**: For example, the local media folder 1752587495 is a folder named after the Unix timestamp of the packet capture, measured when the door is closed again. Or during manual triggering, measured at the request time.
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

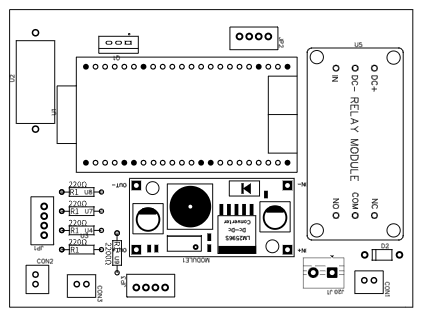
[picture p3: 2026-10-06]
Hardware_Design/PCB_IoT-SQUARE.png

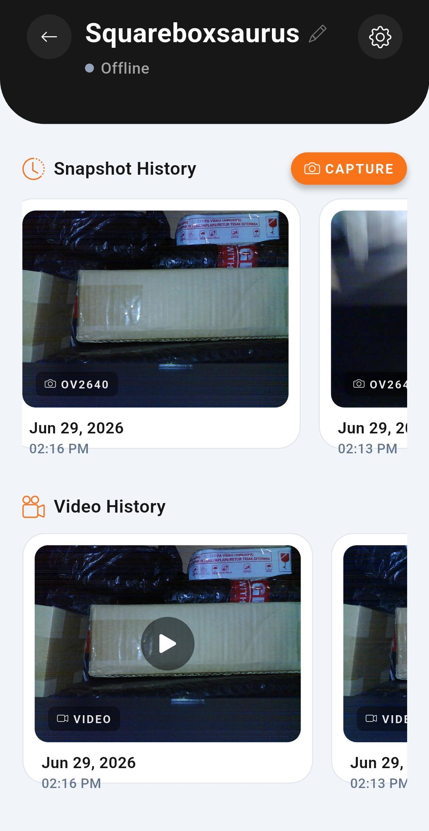
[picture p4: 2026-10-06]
Assets/Video Log Screenshot.jpeg

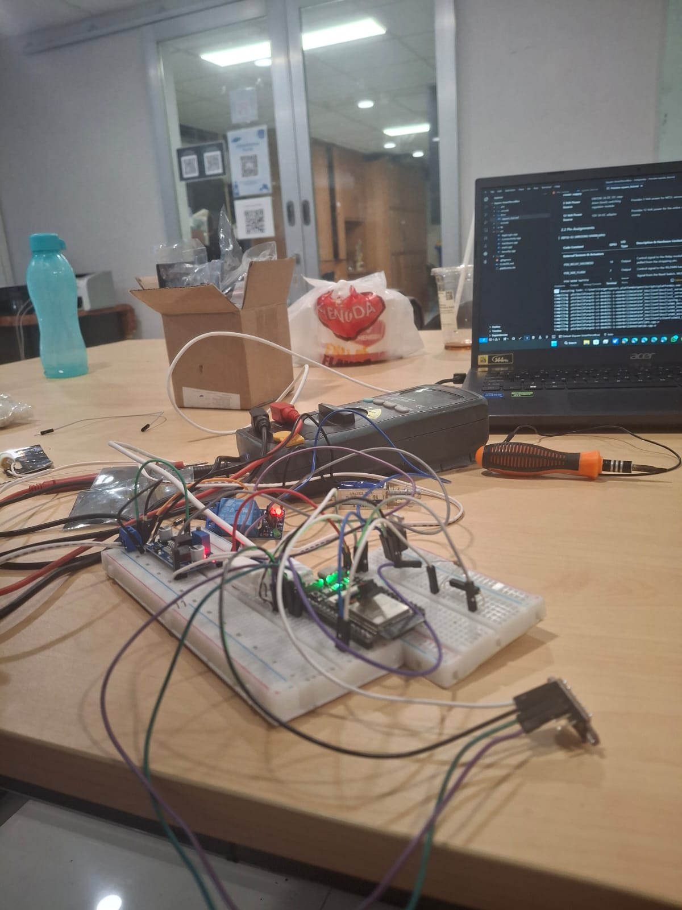
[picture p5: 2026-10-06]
Assets/Breadboard Prototype.jpeg

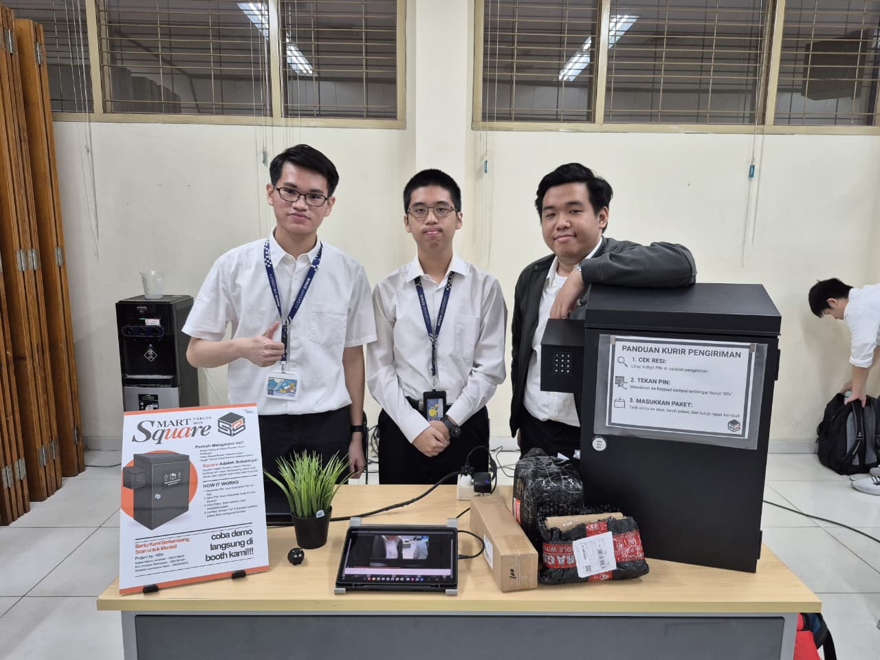
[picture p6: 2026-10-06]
Assets/Booth.jpeg

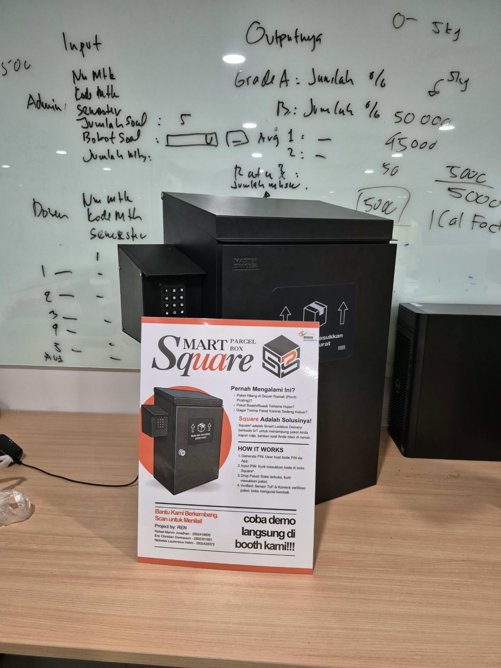
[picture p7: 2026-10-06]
Assets/Final Product.jpeg

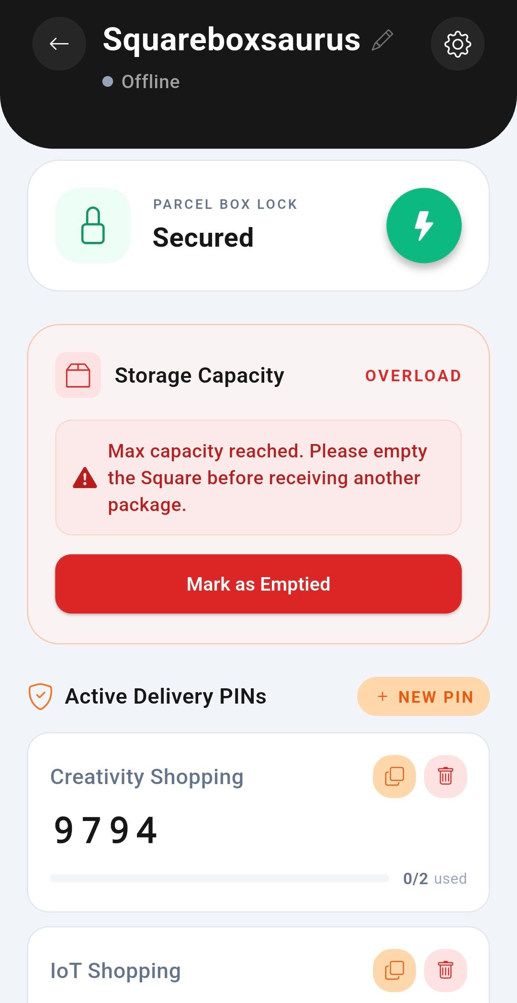
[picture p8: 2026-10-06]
Assets/App Screenshot.jpeg

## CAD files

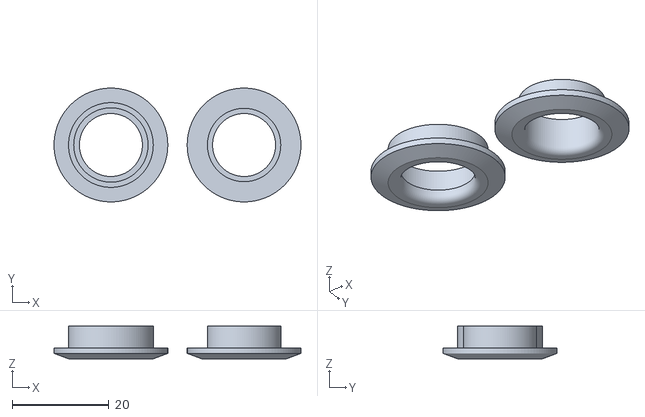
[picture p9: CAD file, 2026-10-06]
Hardware_Design/3D_Files/Grommet.stl
51.0 x 23.5 x 6.75

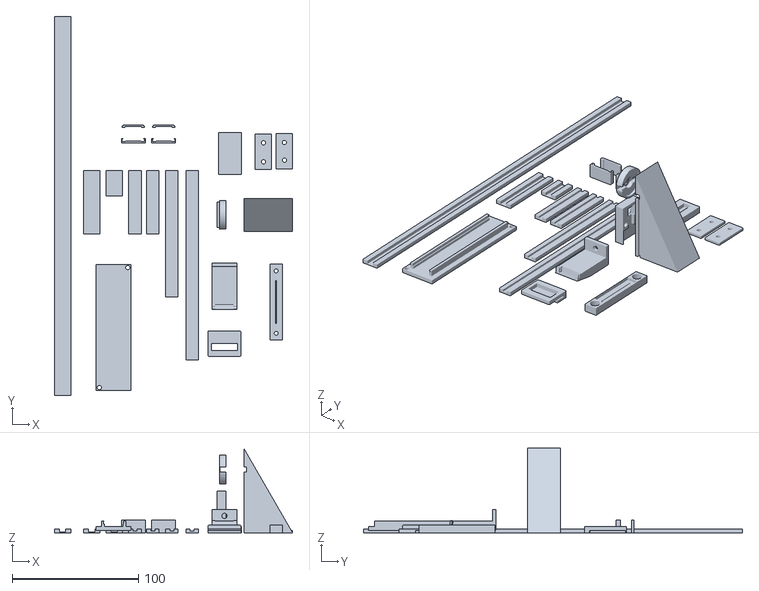
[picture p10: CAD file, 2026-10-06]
Hardware_Design/3D_Files/Cable cover, Camera cover, Magnet Holder, etc.stl
188.6 x 300.0 x 67.0

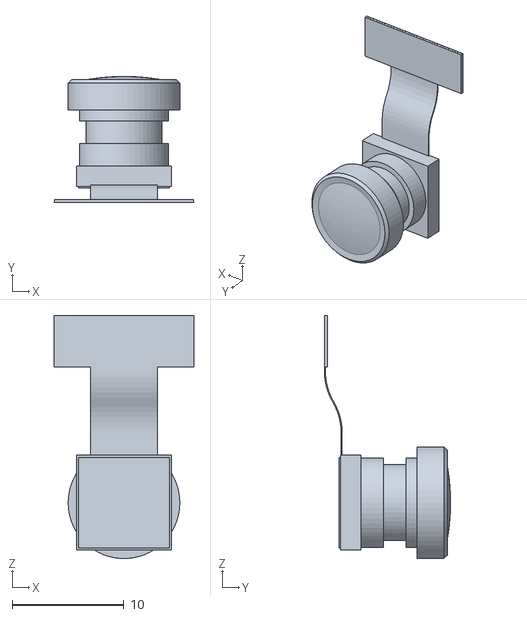
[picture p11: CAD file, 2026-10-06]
Hardware_Design/3D_Files/OV2640_21mm-160_camera.stl
12.5 x 11.3 x 21.7

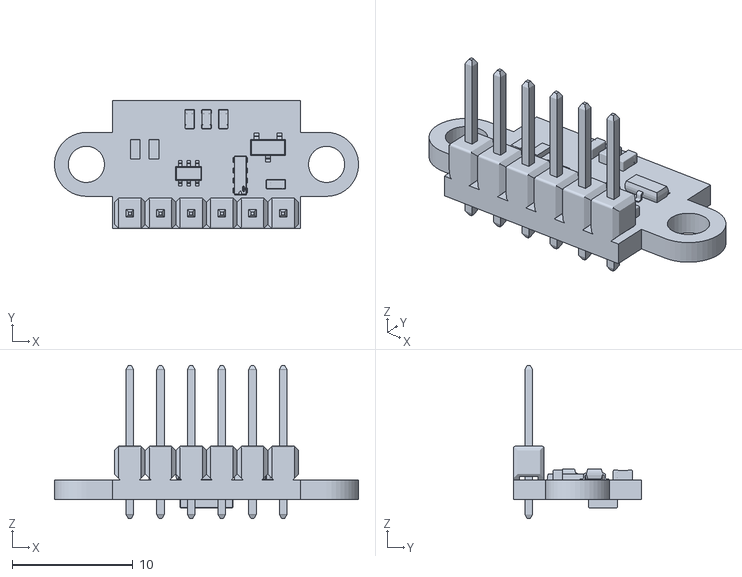
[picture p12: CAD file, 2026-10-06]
Hardware_Design/3D_Files/VL53L0X.stl
25.2 x 10.6 x 12.7

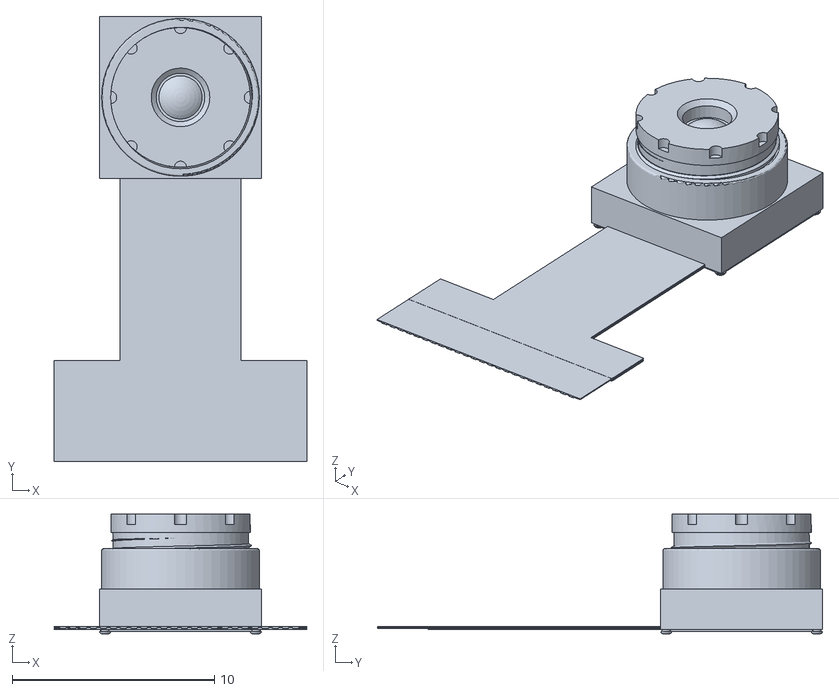
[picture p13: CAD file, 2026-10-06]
Hardware_Design/3D_Files/camera_OV2640_001.stl
12.5 x 22.0 x 5.91

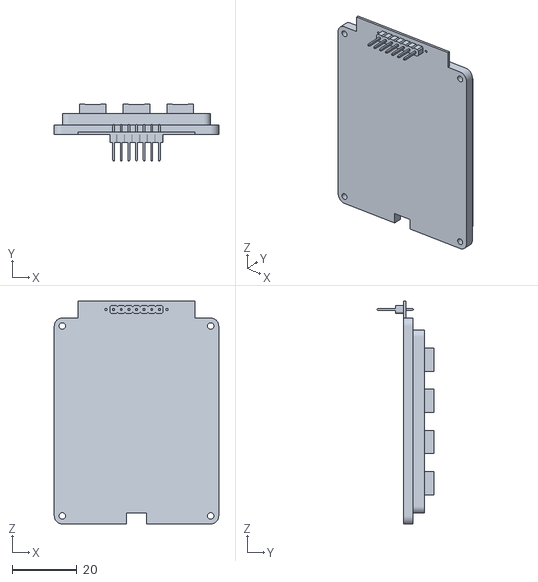
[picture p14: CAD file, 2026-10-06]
Hardware_Design/3D_Files/Keypad.STL
50.9 x 17.7 x 69.0

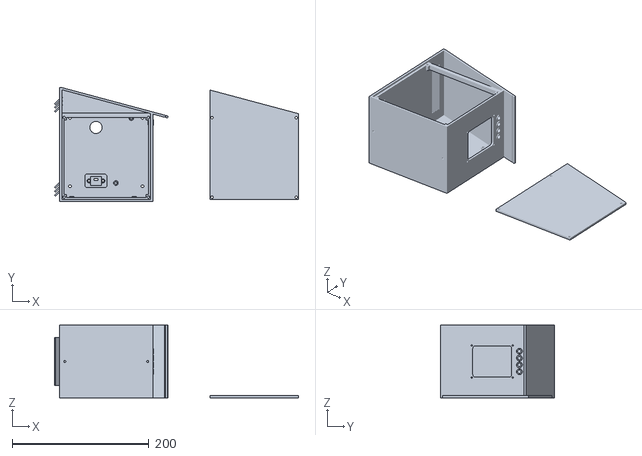
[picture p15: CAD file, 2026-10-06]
Hardware_Design/3D_Files/Case.stl
356.6 x 166.4 x 106.0

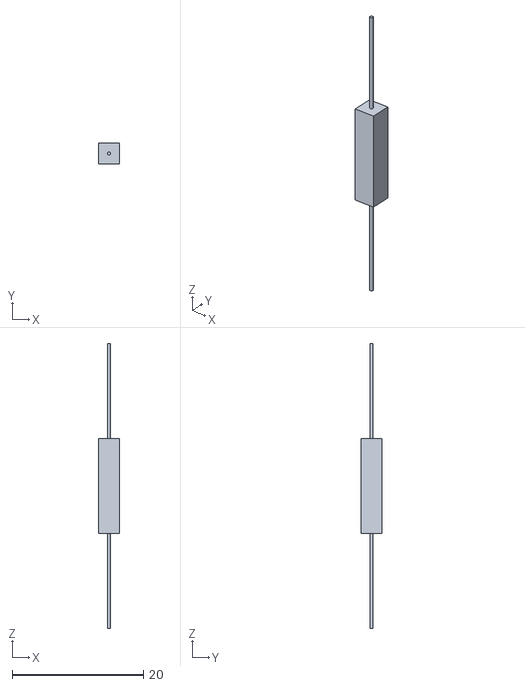
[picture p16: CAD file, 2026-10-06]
Hardware_Design/3D_Files/Reed Switch.stl
3.20 x 3.20 x 43.5

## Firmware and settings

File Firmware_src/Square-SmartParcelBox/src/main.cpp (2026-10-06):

#include <Arduino.h>
#include <WiFi.h>
#include <Wire.h>
#include <freertos/FreeRTOS.h>
#include <freertos/queue.h>
#include <freertos/semphr.h>
#include <freertos/task.h>

// HAL drivers
#include "hal/ws2812.h"
#include "hal/relay.h"
#include "hal/flash_led.h"
#include "hal/reed_switch.h"
#include "hal/keypad_driver.h"
#include "hal/keybuffer_indicator_driver.h"
#include "hal/tof.h"
#include "hal/camera.h"
#include "hal/sdcard.h"
#include "hal/nvs_store.h"

// System headers
#include "pins.h"
#include "config.h"
#include "credentials.h"
#include "state/state_machine.h"
#include "rtos_types.h"

// Firebase
#include "firebase/fb_rtdb.h"
#include "firebase/fb_storage.h"
#include <FirebaseClient.h>

// Task entry points
#include "tasks/task_network.h"
#include "tasks/task_keypad_led.h"
#include "tasks/task_statemachine.h"
#include "tasks/task_media.h"

// ── Global RTOS IPC Objects ─────────────────────────────────────────────────
QueueHandle_t      RTDBQueue    = NULL;
QueueHandle_t      CommandQueue = NULL;
SemaphoreHandle_t  I2C_Mutex    = NULL;
SemaphoreHandle_t  SD_Mutex     = NULL;
SemaphoreHandle_t  NVS_Mutex    = NULL;

extern FirebaseApp app;

// ── Hardware init status tracking ───────────────────────────────────────────
static bool hw_keypad_ok   = false;
static bool hw_led_ind_ok  = false;
static bool hw_tof_ok      = false;
static bool hw_camera_ok   = false;
static bool hw_sdcard_ok   = false;
static bool hw_nvs_ok      = false;
static bool hw_wifi_ok     = false;
static bool hw_firebase_ok = false;

// ── Check if any non-WiFi hardware had issues ───────────────────────────────
static bool has_hw_warnings() {
    return !hw_keypad_ok || !hw_led_ind_ok || !hw_tof_ok || 
           !hw_camera_ok || !hw_sdcard_ok;
}

void setup() {
    Serial.begin(115200);
    while (!Serial) { delay(10); }

    // ── System Banner ───────────────────────────────────────────────────────
    Serial.println("[INFO] [SYSTEM] =============================================");
    Serial.println("[INFO] [SYSTEM] Square - Smart Parcel Box by REN");
    Serial.println("[INFO] [SYSTEM] =============================================");
    Serial.println("[INFO] [SYSTEM] Starting up. WS2812 pattern: RED-BLUE-BLINK");

    // ── Initialize WS2812 first (startup indicator) ─────────────────────────
    ws2812_init();
    ws2812_set_pattern(WS2812_RED_BLUE_BLINK);

    // ── Initialize I2C bus ──────────────────────────────────────────────────
    Wire.begin(PIN_SDA, PIN_SCL);

    // ── Initialize relay (starts locked = safe default per SFS-001) ─────────
    relay_init();

    // ── Initialize flash LED ────────────────────────────────────────────────
    flash_led_init();

    // ── Initialize reed switch ──────────────────────────────────────────────
    reed_switch_init();

    // ── Initialize Keypad via PCF8574 at 0x20 ───────────────────────────────
    hw_keypad_ok = keypad_init(Wire);
    Serial.printf("[INFO] [HARDWARE] Init Keypad PCF8574 at 0x20: %s\n", hw_keypad_ok ? "SUCCESS" : "FAILED");

    // ── Initialize LED Indicator via PCF8574 at 0x21 ────────────────────────
    hw_led_ind_ok = led_indicator_init(Wire);
    Serial.printf("[INFO] [HARDWARE] Init LED PCF8574 at 0x21: %s\n", hw_led_ind_ok ? "SUCCESS" : "FAILED");

    // ── Initialize ToF sensor VL53L0X at 0x29 ───────────────────────────────
    hw_tof_ok = tof_init(Wire);
    Serial.printf("[INFO] [HARDWARE] Init ToF VL53L0X at 0x29: %s\n", hw_tof_ok ? "SUCCESS" : "FAILED");

    // ── Initialize Camera OV2640 ────────────────────────────────────────────
    hw_camera_ok = camera_init();
    Serial.printf("[INFO] [HARDWARE] Init OV2640 Camera: %s\n", hw_camera_ok ? "SUCCESS" : "FAILED");

    // ── Initialize NVS ──────────────────────────────────────────────────────
    hw_nvs_ok = nvs_store_init();
    if (hw_nvs_ok) {
        // DBG-011: Only display pin count if NVS init succeeded
        int pin_count = nvs_store_get_pin_count();
        Serial.printf("[INFO] [NVS] Init NVS: SUCCESS. Found %d active pins.\n", pin_count);
    } else {
        Serial.println("[INFO] [NVS] Init NVS: FAILED.");
    }

    // ── Initialize MicroSD Card ─────────────────────────────────────────────
    hw_sdcard_ok = sdcard_init();
    if (hw_sdcard_ok) {
        // DBG-010: Only display card info if init succeeded
        Serial.printf("[INFO] [SD_CARD] Init MicroSD: SUCCESS. Type: %s, Size: %u MB.\n",
                      sdcard_get_type_string(), sdcard_get_size_mb());
        // DBG-008: Perform write-read verification test
        bool write_test = sdcard_write_test();
        Serial.printf("[INFO] [SD_CARD] Performing write test: %s\n", write_test ? "PASSED" : "FAILED");
        if (!write_test) hw_sdcard_ok = false;
    } else {
        Serial.println("[INFO] [SD_CARD] Init MicroSD: FAILED.");
    }

    // ── Create RTOS IPC Objects ──────────────────────────────────────────────
    RTDBQueue    = xQueueCreate(RTDB_QUEUE_DEPTH, sizeof(RTDBWriteRequest));
    CommandQueue = xQueueCreate(COMMAND_QUEUE_DEPTH, sizeof(RemoteCommand));
    I2C_Mutex    = xSemaphoreCreateMutex();
    SD_Mutex     = xSemaphoreCreateMutex();
    NVS_Mutex    = xSemaphoreCreateMutex();

    if (!RTDBQueue || !CommandQueue || !I2C_Mutex || !SD_Mutex || !NVS_Mutex) {
        Serial.println("[ERROR] [SYSTEM] Failed to create RTOS IPC objects!");
    }

    // ── Initialize State Machine ────────────────────────────────────────────
    sm_init();

    // ── Network Initialization (WiFi + NTP + Firebase) ──────────────────────
    if (hw_led_ind_ok) {
        led_indicator_alternating_pattern();
        Serial.println("[INFO] [SYSTEM] LED Expander alternating pattern: ON");
    }

    hw_wifi_ok = false;
    hw_firebase_ok = false;

    Serial.printf("[INFO] [WIFI] Connecting to %s (1/%d)...\n", WIFI_SSID, WIFI_MAX_RETRIES);
    WiFi.begin(WIFI_SSID, WIFI_PASSWORD);
    int retries = 0;
    while (WiFi.status() != WL_CONNECTED && retries < WIFI_MAX_RETRIES) {
        delay(WIFI_RETRY_DELAY_MS);
        retries++;
        if (retries % 5 == 0 && retries < WIFI_MAX_RETRIES) {
            Serial.printf("[INFO] [WIFI] Connecting to %s (%d/%d)...\n", WIFI_SSID, retries + 1, WIFI_MAX_RETRIES);
        }
    }

    if (WiFi.status() == WL_CONNECTED) {
        hw_wifi_ok = true;
        Serial.printf("[SUCCESS] [WIFI] Connected. IP: %s\n", WiFi.localIP().toString().c_str());
        Serial.printf("[INFO] [WIFI] Init Wi-Fi module: SUCCESS. MAC: %s\n", fb_rtdb_get_mac_address().c_str());
        
        ws2812_set_pattern(WS2812_SOLID_BLUE);
        Serial.println("[INFO] [SYSTEM] WS2812 Set to: SOLID_BLUE.");
        
        if (hw_led_ind_ok) {
            led_indicator_stop_pattern();
            led_indicator_set_count(0);
            Serial.println("[INFO] [SYSTEM] LED Expander alternating pattern: OFF");
        }

        configTime(7 * 3600, 0, "pool.ntp.org", "id.pool.ntp.org");
        struct tm timeinfo;
        if(getLocalTime(&timeinfo, 5000)) {
            Serial.println("[INFO] [SYSTEM] Syncing NTP pool.ntp.org: SUCCESS");
        } else {
            Serial.println("[INFO] [SYSTEM] Syncing NTP pool.ntp.org: FAILED");
        }

        hw_firebase_ok = fb_rtdb_init();
    } else {
        Serial.printf("[INFO] [WIFI] Connecting to %s (%d/%d)... FAILED.\n", WIFI_SSID, WIFI_MAX_RETRIES, WIFI_MAX_RETRIES);
        if (hw_led_ind_ok) {
            led_indicator_stop_pattern();
            led_indicator_set_count(0);
            Serial.println("[INFO] [SYSTEM] LED Expander alternating pattern: OFF");
        }
    }

    // ── Determine final system state based on init results ───────────────────
    // Per FSD §6.6 and §6.7:
    if (hw_firebase_ok) {
        // Firebase connected — initialize storage and create device entry
        fb_storage_init();
        fb_rtdb_create_device_entry();
        fb_rtdb_update_heartbeat();

        if (has_hw_warnings()) {
            // Connected but hardware issues (except WiFi)
            ws2812_set_pattern(WS2812_SOLID_YELLOW);
            Serial.println("[INFO] [SYSTEM] WS2812 Set to: SOLID_YELLOW.");
            Serial.println("[INFO] [SYSTEM] Initialization completed with warnings. -> [STATE_IDLE]");
        } else {
            // Everything OK
            ws2812_set_pattern(WS2812_SOLID_GREEN);
            Serial.println("[INFO] [SYSTEM] WS2812 Set to: SOLID_GREEN.");
            Serial.println("[INFO] [SYSTEM] Initialization completed. -> [STATE_IDLE]");
        }
        sm_transition_to(STATE_IDLE);

    } else {
        // WiFi or Firebase failed — check NVS for offline operation
        Serial.println("[WARN] [FIREBASE] Network unavailable. Skipping authentication.");

        int active_pins = 0;
        if (hw_nvs_ok) {
            active_pins = nvs_store_get_pin_count();
        }

        if (hw_nvs_ok && active_pins > 0) {
            // Offline mode with active PINs — can still authenticate locally
            Serial.printf("[INFO] [NVS] Checking active pins... Found %d active pins. There's still hope!\n", active_pins);
            ws2812_set_pattern(WS2812_SOLID_PURPLE);
            Serial.println("[WARN] [SYSTEM] Entering Offline Mode. WS2812 Set to: SOLID_PURPLE.");
            Serial.println("[INFO] [SYSTEM] Initialization completed with warnings. -> [STATE_IDLE]");
            sm_transition_to(STATE_IDLE);
        } else {
            // Total isolation — no network AND no local PINs
            if (!hw_nvs_ok) {
                Serial.println("[INFO] [NVS] NVS failed to initialize.");
            } else {
                Serial.println("[INFO] [NVS] Checking active pins... 0 active pins found.");
            }
            Serial.println("[ERROR] [SYSTEM] No network and no active pins! System isolated.");
            ws2812_set_pattern(WS2812_SOLID_RED);
            Serial.println("[ERROR] [SYSTEM] WS2812 Set to: SOLID_RED.");
            Serial.println("[INFO] [SYSTEM] Halting operations. -> [STATE_ERROR]");
            sm_transition_to(STATE_ERROR);
        }
    }

    // ── Create FreeRTOS Tasks (per FSD §6.4) ────────────────────────────────
    // Tasks are created regardless of state — they check sm_get_state() internally
    xTaskCreatePinnedToCore(task_network_entry,     "Task_Network",     8192, NULL, 2, NULL, 0);
    xTaskCreatePinnedToCore(task_keypad_led_entry,   "Task_Keypad_LED",  4096, NULL, 4, NULL, 1);
    xTaskCreatePinnedToCore(task_sm_entry,           "Task_StateMachine", 8192, NULL, 3, NULL, 1);
    xTaskCreatePinnedToCore(task_media_entry,         "Task_Media",       8192, NULL, 1, NULL, 1);

    // Enable keypad scanning (only if we're in IDLE state)
    if (sm_get_state() == STATE_IDLE) {
        task_keypad_led_set_enabled(true);
    }

    Serial.println("[INFO] [SYSTEM] All FreeRTOS tasks created. Scheduler running.");
}

// ── Arduino loop() — empty in production RTOS architecture ──────────────────
// All work is handled by FreeRTOS tasks.
void loop() {
    vTaskDelay(pdMS_TO_TICKS(1000));
}

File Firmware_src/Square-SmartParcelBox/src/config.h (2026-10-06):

#ifndef CONFIG_H
#define CONFIG_H

// Time-of-Flight Sensor settings
#define TOF_TOLERANCE_CM 5 // Revised by me from implementation phase 0 plan, using the tolerance instead of threshold.
#define TOF_BOX_WIDTH_CM 40 // The box width, as the reference.

// Timeouts and Intervals
#define DOOR_TIMEOUT_MS 10000 // Timeout waiting for courier to open the door after unlocked.
#define HEARTBEAT_INTERVAL_MS 30000 // Interval for heartbeat, sent every 30 seconds to be compared by apps. if the difference is more than 1 minute, then the system is offline.
#define WIFI_MAX_RETRIES 25
#define WIFI_RETRY_DELAY_MS 300
#define FLASH_WARMUP_MS 1000

// SD Card and queues
#define SD_MIN_FREE_MB 50 // Minimum empty space (in MB) for MicroSD. If during checking process below this value, then paired FIFO of MicroSD content is triggered.
#define RTDB_QUEUE_DEPTH 10
#define COMMAND_QUEUE_DEPTH 3

// Retry delays for offline uploads
#define RETRY_FIRST_FAIL_MS 300000 // 5 minutes waiting time before the second attempt of delivery logs push 
#define RETRY_SUBSEQUENT_MS 900000

// Debouncing and blink rates
#define KEYPAD_DEBOUNCE_MS 200
#define LED_ALT_INTERVAL_MS 250
#define ERROR_LOG_INTERVAL_MS 1000
#define WS2812_BLINK_INTERVAL_MS 1000
#define RTOS_MIN_DELAY_MS 10

// Automatic auth trigger at how many digits inputted
#define PIN_LENGTH 4

#endif // CONFIG_H

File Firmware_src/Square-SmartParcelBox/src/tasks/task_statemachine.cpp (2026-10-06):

#include "task_statemachine.h"
#include <freertos/FreeRTOS.h>
#include <freertos/queue.h>
#include <freertos/semphr.h>

#include "../state/state_machine.h"
#include "../rtos_types.h"
#include "../config.h"

// HAL headers
#include "../hal/relay.h"
#include "../hal/reed_switch.h"
#include "../hal/tof.h"
#include "../hal/nvs_store.h"
#include "../hal/ws2812.h"
#include "../hal/camera.h"
#include "../hal/sdcard.h"

// Firebase headers
#include "../firebase/fb_rtdb.h"

// Sibling task headers
#include "task_keypad_led.h"
#include "task_media.h"

// HAL driver for LED indicator (used in invalid PIN feedback)
#include "../hal/keybuffer_indicator_driver.h"

// ── Extern IPC objects (owned by main.cpp) ──────────────────────────────────
extern QueueHandle_t      RTDBQueue;
extern QueueHandle_t      CommandQueue;
extern SemaphoreHandle_t  I2C_Mutex;
extern SemaphoreHandle_t  SD_Mutex;
extern SemaphoreHandle_t  NVS_Mutex;

// ── File-scope state ────────────────────────────────────────────────────────
static String s_ondemand_timestamp = "";   // App-provided timestamp for on-demand photo
static bool fifo_cleanup_done = false;     // CVL-009: FIFO cleanup runs ONCE per IDLE entry

// ── Forward declarations ────────────────────────────────────────────────────
static void handle_idle();
static void handle_delivery(const char* pin_used);
static void handle_ondemand();
static void handle_error();
static void handle_remote_command(RemoteCommand cmd);
static void enqueue_rtdb(RTDBWriteType type, const char* key, const char* value_str, bool value_bool, int value_int = 0);

// ── Task entry point ────────────────────────────────────────────────────────
void task_sm_entry(void* pvParameters) {
    (void)pvParameters;

    Serial.println("[INFO] [SYSTEM] State-machine task started");

    while (1) {
        vTaskDelay(pdMS_TO_TICKS(RTOS_MIN_DELAY_MS));

        switch (sm_get_state()) {
            case STATE_IDLE:
                handle_idle();
                break;
            case STATE_DELIVERY:
                // Should not land here directly — delivery is entered via handle_idle
                break;
            case STATE_ONDEMAND:
                handle_ondemand();
                break;
            case STATE_ERROR:
                handle_error();
                break;
            default:
                // STATE_START — waiting for main.cpp to transition to IDLE
                break;
        }
    }
}

// ── handle_idle ─────────────────────────────────────────────────────────────
static void handle_idle() {
    // CVL-009: FIFO cleanup runs ONCE after entering STATE_IDLE
    if (!fifo_cleanup_done) {
        if (sdcard_is_available()) {
            xSemaphoreTake(SD_Mutex, portMAX_DELAY);
            sdcard_fifo_cleanup();
            xSemaphoreGive(SD_Mutex);
            Serial.println("[INFO] [SD_CARD] FIFO cleanup completed.");
        }
        fifo_cleanup_done = true;
    }

    // 1. Check if keypad buffer is full (4-digit PIN entered)
    if (task_keypad_led_is_buffer_full()) {
        const char* pin = task_keypad_led_get_buffer();
        Serial.printf("[INFO] [KEYPAD] Courier input buffer complete: %s\n", pin);
        Serial.printf("[INFO] [NVS] Verifying PIN %s with NVS...\n", pin);

        // Verify PIN using NVS (NVS is the source of truth)
        xSemaphoreTake(NVS_Mutex, portMAX_DELAY);
        bool valid = nvs_store_verify_pin(pin);
        xSemaphoreGive(NVS_Mutex);

        if (valid) {
            Serial.printf("[SUCCESS] [NVS] PIN %s is correct!\n", pin);

            // Copy pin before clearing buffer
            char pin_copy[PIN_LENGTH + 1];
            strncpy(pin_copy, pin, PIN_LENGTH);
            pin_copy[PIN_LENGTH] = '\0';

            task_keypad_led_clear_buffer();
            task_keypad_led_set_enabled(false);

            Serial.println("[INFO] [SYSTEM] Transitioning -> [STATE_DELIVERY]");
            sm_transition_to(STATE_DELIVERY);
            fifo_cleanup_done = false;  // Reset so FIFO cleanup runs on next IDLE entry
            handle_delivery(pin_copy);
        } else {
            Serial.println("[WARN] [NVS] Incorrect PIN. Resetting buffer.");
            task_keypad_led_clear_buffer();

            // Brief flash pattern to indicate invalid PIN
            xSemaphoreTake(I2C_Mutex, portMAX_DELAY);
            led_indicator_alternating_pattern();
            xSemaphoreGive(I2C_Mutex);

            vTaskDelay(pdMS_TO_TICKS(LED_ALT_INTERVAL_MS * 4));

            xSemaphoreTake(I2C_Mutex, portMAX_DELAY);
            led_indicator_stop_pattern();
            xSemaphoreGive(I2C_Mutex);
        }
    }

    // 2. Check CommandQueue (non-blocking)
    RemoteCommand cmd;
    if (xQueueReceive(CommandQueue, &cmd, 0) == pdTRUE) {
        handle_remote_command(cmd);
    }

    // SFS-010: Check for total isolation (no PINs + offline)
    if (!fb_rtdb_is_connected()) {
        xSemaphoreTake(NVS_Mutex, portMAX_DELAY);
        int pin_count = nvs_store_get_pin_count();
        xSemaphoreGive(NVS_Mutex);

        if (pin_count <= 0) {
            Serial.println("[ERROR] [SYSTEM] No local active pins, no connection to Firebase.");
            sm_transition_to(STATE_ERROR);
            return;
        }
    }
}
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

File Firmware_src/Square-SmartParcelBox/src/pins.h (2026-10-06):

#ifndef PINS_H
#define PINS_H

// WS2812 RGB LED
#define PIN_LED_WS2812 48

// Relay Solenoid
#define PIN_RELAY_SOLENOID 14

// Auxiliary Flash LED
#define PIN_AUX_FLASH 2

// Door Switch (Reed Switch)
#define PIN_DOOR_SWITCH 1

// I2C Pins
#define PIN_SDA 21
#define PIN_SCL 47

// I2C Addresses
#define I2C_ADDR_KEYPAD 0x20
#define I2C_ADDR_LED_IND 0x21
#define I2C_ADDR_TOF 0x29

// Camera Module Interface (OV2640)
#define PIN_CAM_D0 11
#define PIN_CAM_D1 9
#define PIN_CAM_D2 8
#define PIN_CAM_D3 10
#define PIN_CAM_D4 12
#define PIN_CAM_D5 18
#define PIN_CAM_D6 17
#define PIN_CAM_D7 16
#define PIN_CAM_XCLK 15
#define PIN_CAM_PCLK 13
#define PIN_CAM_VSYNC 6
#define PIN_CAM_HREF 7
#define PIN_CAM_SIOD 4
#define PIN_CAM_SIOC 5

// MicroSD Card
#define PIN_SD_DATA 40
#define PIN_SD_CLK 39
#define PIN_SD_CMD 38

#endif // PINS_H
